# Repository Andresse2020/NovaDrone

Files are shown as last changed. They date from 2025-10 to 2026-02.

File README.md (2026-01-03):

# NovaDrone

Copyright © 2025 Andresse Brisel BASSINGA
Licensed under CERN Open Hardware Licence v2 – Weakly Reciprocal (CERN-OHL-W)

This project provides a complete hardware design for a professional UAV Quadcopter.
Firmware is proprietary and not covered by this licence.

## Project Overview
NovaDrone is a full hardware–firmware engineering project aiming to develop the **entire embedded electronics** of a quadcopter UAV **from scratch**.  
Rather than relying on off-the-shelf components, the project focuses on designing all critical subsystems: propulsion electronics, real-time motor control, power supervision, communication, diagnostics, and later, a fully custom flight controller.

The objective is to create a **professional-grade, reliable, and modular UAV platform** suitable for demanding embedded applications in robotics and aerospace.

---

## Key Features

- **Custom 1.5 kW Propulsion Board**  
  Single PCB integrating four 300–400 W ESCs and a dedicated supervisor MCU.

- **High-Performance ESC Subsystems**  
  STM32G4-based motor controllers using sensorless FOC, 48 kHz PWM, synchronized ADC sampling, and real-time telemetry.

- **Supervisor MCU**  
  Active precharge, power sequencing, battery monitoring, ARM/DISARM logic, watchdog, kill-line, USB monitoring, and DroneCAN communication.

- **Integrated Power Management**  
  LC filtering, TVS protection, OVP/UVLO/OCP/OTP, reinforced copper, and regulated 12 V / 5 V / 3.3 V rails.

- **Communication Architecture**  
  DroneCAN (CAN-FD) for propulsion telemetry and commands, UART CLI for debugging, USB streaming during development.

- **Custom Flight Controller (Next Stage)**  
  IMU fusion, stabilization, navigation logic, modular firmware architecture.

---

## Starting Point

NovaDrone uses a robust quadcopter frame as a mechanical platform for integration and testing:

- **Frame:** ZD550 carbon fiber  
- **Motors:** QM4208 brushless motors  
- **Propellers:** 1455 carbon fiber  

All electronics, power systems, and firmware are entirely custom-designed.

---

## Project Goals

NovaDrone aims to develop a **complete UAV electronics and firmware stack**, with emphasis on:

- High-efficiency propulsion and motor control  
- Intelligent and safe power management  
- Clean and maintainable firmware architecture  
- Robust diagnostics and system telemetry  
- Modular and scalable embedded design  
- Full control over every subsystem (no black boxes)

This is not a drone assembly project—**every subsystem is engineered from the ground up**.

---

## Architecture

### 1. Propulsion Board (1.5 kW)
A single PCB containing all propulsion-related electronics.

**Includes:**
- 4 × ESC (STM32G4)  
- 1 × Supervisor MCU  
- PSU: 12 V / 5 V / 3.3 V  
- Active precharge circuit  
- LC filtering, TVS, fuses  
- CAN-FD transceivers  
- USB and UART  
- XT60 (battery), XT30PW (motors), JST PH/SH, Tag-Connect SWD

---

### 2. ESC Subsystems (300–400 W each)

Each ESC is a fully independent motor controller.

**Features:**
- STM32G4 ARM Cortex-M4  
- Sensorless FOC  
- 48 kHz PWM  
- 24 kHz current loop  
- 1 kHz speed loop  
- Synchronized ADC sampling  
- Low-noise current sensing  
- Telemetry (current, voltage, RPM, temperature)  
- Bare-metal firmware (no HAL)

---

### 3. Supervisor MCU

Handles global power management and safety.

**Functions:**
- Active precharge (anti-inrush)  
- Battery voltage/current/temperature monitoring  
- Power sequencing  
- ARM/DISARM logic  
- Watchdog and kill-line  
- DroneCAN (CAN-FD) communication  
- **USB interface for development-time monitoring**  
- UART CLI  
- Planned: CAN bootloader

---

### 4. Integrated Power Management

Built directly into the propulsion board.

**Includes:**
- Input: LiPo 6S (18–25 V)  
- LC input filtering (PI filter)  
- TVS surge protection  
- OVP, UVLO, OCP, OTP protections  
- Reinforced copper planes  
- Regulated power rails (12 V / 5 V / 3.3 V)

---

### 5. Flight Control Unit (Upcoming)

The FCU will be developed after propulsion system validation.

**Planned capabilities:**
- STM32-based processing  
- IMU, barometer, magnetometer, GPS fusion  
- Kalman-based estimation  
- Stabilization loops  
- Trajectory and navigation control  

---

### 6. Communication System

| Interface | Purpose |
|---|---|
| **DroneCAN (CAN-FD)** | ESC commands, propulsion telemetry, supervisor data |
| **USB** | High-rate logging and real-time monitoring during development |
| **UART CLI** | Debugging, tuning, calibration |
| **SWD** | Low-level flashing and debugging |

---

## Development Environment

NovaDrone firmware uses a custom modular embedded development environment built with **CMake**.

## Licence

Hardware design files are licensed under the CERN Open Hardware Licence v2 – Weakly Reciprocal (CERN-OHL-W).

The firmware is proprietary and not covered by this licence.
Commercial licences are available on request.

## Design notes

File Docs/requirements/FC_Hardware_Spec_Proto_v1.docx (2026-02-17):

HARDWARE SPECIFICATION

Flight Controller — Prototype v1

Parameter | Value
Document ID | HW-SPEC-PROTO-001
Version | 1.0 — Draft
Date | February 2026
Parent document | SYS-REQ-001
Status | Draft
Certification | Not certified — internal validation prototype only

# 1. Purpose

This document specifies the hardware requirements for the design and manufacture of the Flight Controller (FC) Prototype v1. It is intended for the hardware engineer responsible for PCB design, layout, and assembly.

The prototype serves to validate hardware choices prior to the certified DAL-B production design. It is not subject to DO-254 certification at this stage.

# 2. System Architecture

The FC system consists of three separate PCBs interconnected via board-to-board connectors:

Board | PCB Size | Role
FCU (Main Board) | 100 × 100 mm | MCU, inertial sensors, power interfaces, communication
GNSS + Compass Module | External module | u-blox ZOE-M8Q + AK09918C
Remote Control Module | External module | ExpressLRS SX1280 + ESP32-C3

- GNSS and RC modules connect to the FCU via board-to-board stacking connectors (left and right sides of the FCU)
- All three PCBs are 4-layer

## 2.1 Block Diagram

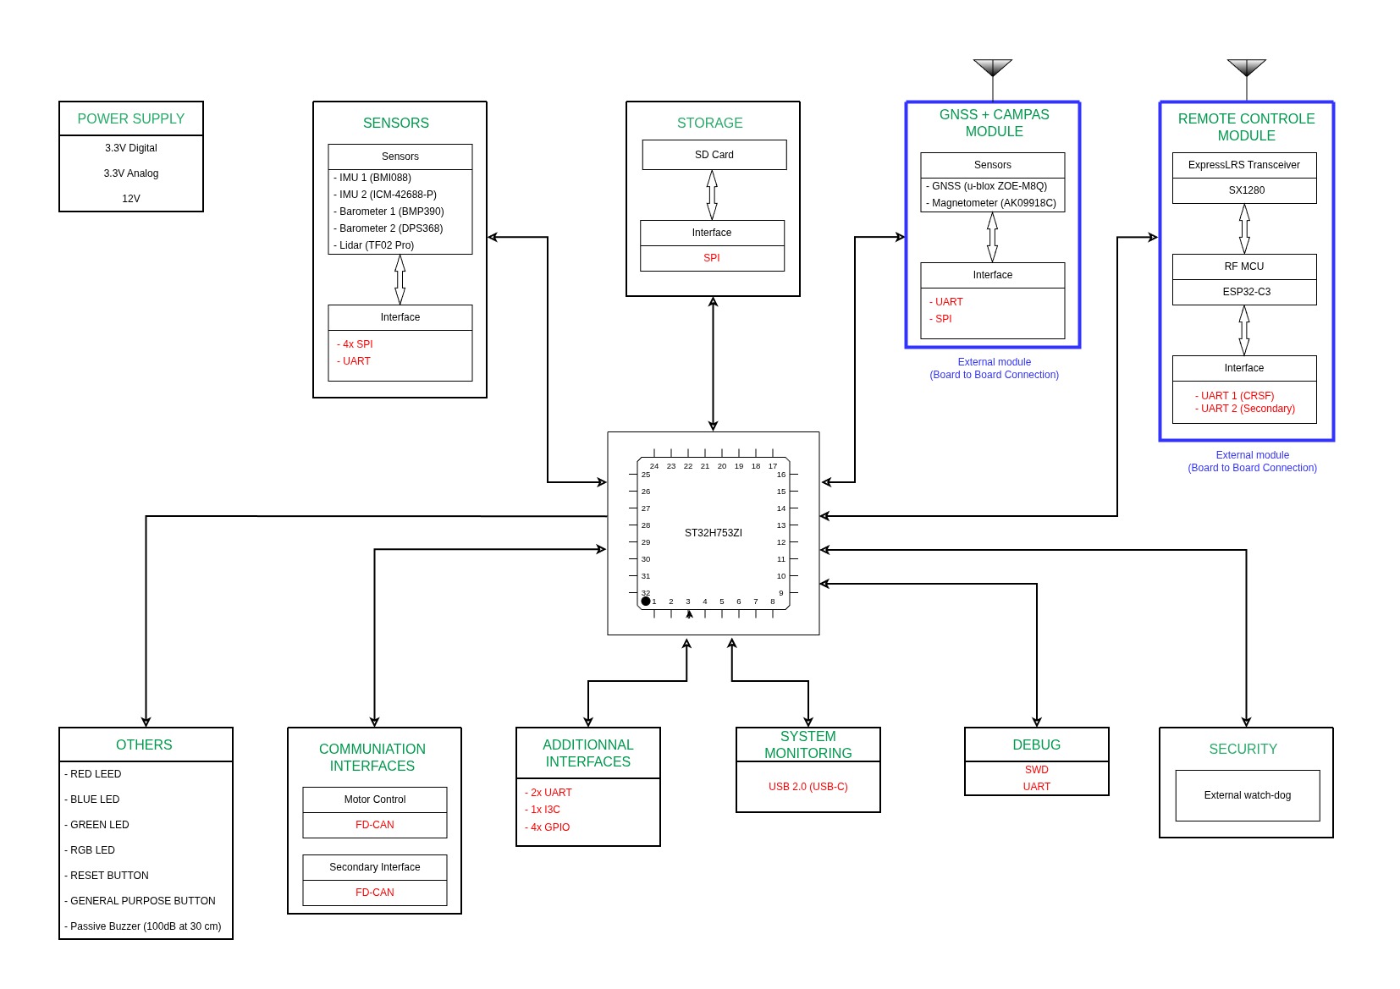
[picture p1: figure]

Figure 1 — FC System Block Diagram

## 2.2 Mechanical Layout

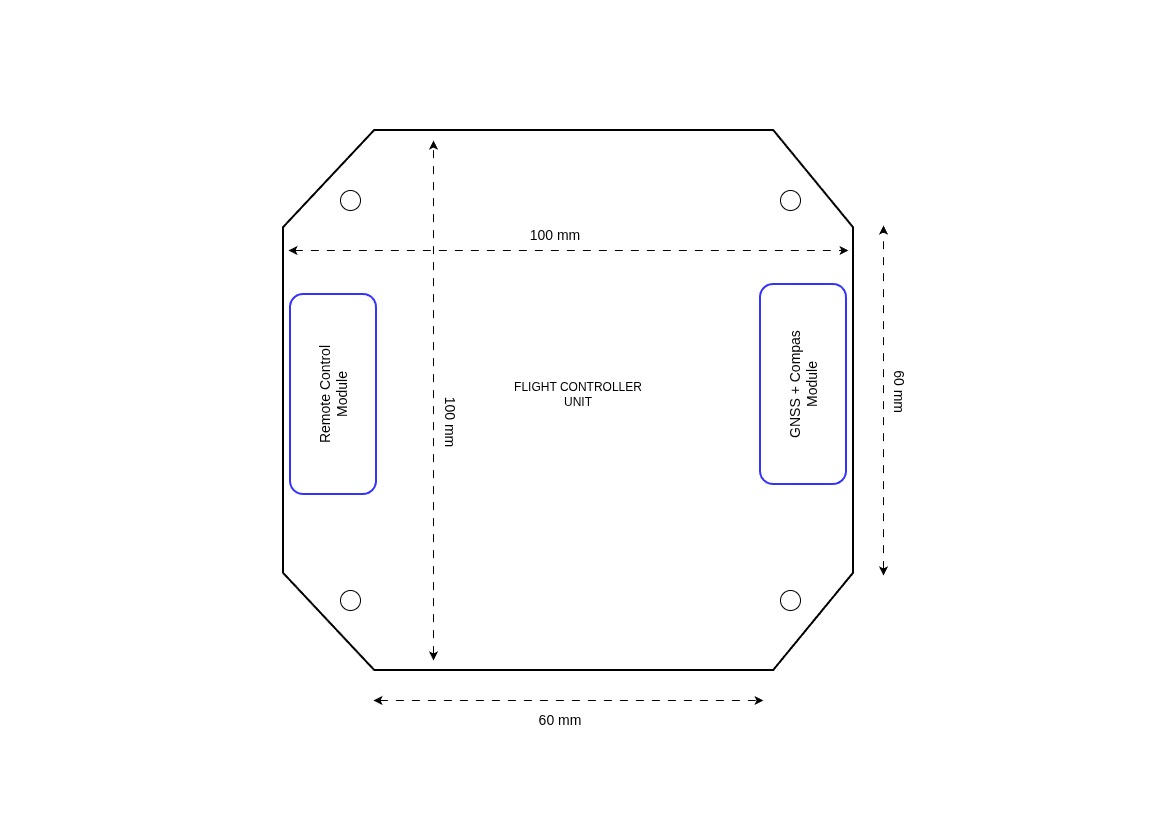
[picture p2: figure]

Figure 2 — FCU Board Layout (100 × 100 mm octagonal, modules on left and right sides)

# 3. Fixed Components

The following critical components are imposed. No substitution without prior validation.

## 3.1 FCU — Main Board

Microcontroller

Parameter | Value
MCU | ST32H753ZI
Architecture | ARM Cortex-M7 @ 480 MHz — hardware double-precision FPU
Justification | 16D EKF @ 1 kHz — SYS-REQ-F-010, SYS-REQ-F-013

Inertial Sensors — Redundancy Required (SYS-REQ-F-001)

Reference | Component | Bus | Rate | Notes
IMU 1 | BMI088 | SPI | ≥ 1 kHz | Gyro + Accel
IMU 2 | ICM-42688-P | SPI | ≥ 1 kHz | Gyro + Accel
Barometer 1 | BMP390 | SPI | ≥ 50 Hz
Barometer 2 | DPS368 | SPI | ≥ 50 Hz

IMPORTANT: Both IMUs and both barometers must be mounted on vibration isolation pads (soft-mount).

Distance Sensor

Reference | Component | Bus | Rate
Lidar | TF02 Pro | UART | ≥ 50 Hz — SYS-REQ-F-001

## 3.2 GNSS + Compass Module (external board)

Reference | Component | Interface to FCU | Rate
GNSS | u-blox ZOE-M8Q | UART | ≥ 5 Hz — SYS-REQ-F-001
Magnetometer | AK09918C | SPI | ≥ 50 Hz — SYS-REQ-F-001

- External GNSS antenna via U.FL or SMA connector
- Module positioned on the right/left side of the FCU (see Figure 2)

## 3.3 Remote Control Module (external board)

Reference | Component | Interface to FCU | Notes
RF Transceiver | SX1280 | SPI (via ESP32-C3) | ExpressLRS — SYS-REQ-IF-001
RF MCU | ESP32-C3 | UART CRSF to FCU | Primary CRSF protocol

- FCU interfaces: UART 1 (CRSF primary) + UART 2 (secondary)
- Module positioned on the left/right side of the FCU (see Figure 2)

# 4. Power Supply

The FCU has no direct access to the battery. All power rails are supplied by the propulsion board via dedicated JST-PH 2-pin connectors (one per rail). Maximum current per rail: 2A.

Rail | Voltage | Max Current | Connector | Usage
3.3V Digital | 3.3V regulated | 2A | JST-PH 2-pin | MCU, digital sensors, logic
3.3V Analog | 3.3V regulated | 2A | JST-PH 2-pin | Analog sensors, MCU ADC — filtered, isolated from digital rail
12V Regulated | 12V regulated | 2A | JST-PH 2-pin | Buzzer, peripherals

NOTE: The FCU does not include any DC-DC converters or LDOs for these rails. The three JST-PH connectors are the sole power inputs from the propulsion board. Current monitoring is not available on the FCU side.

Battery voltage and current monitoring (SYS-REQ-PWR-001/002) are provided by the propulsion board and transmitted to the FCU via CAN bus.

# 5. PCB Specifications

Parameter | Specification
FCU dimensions | 100 × 100 mm — octagonal shape (chamfered corners)
Module dimensions | Not specified
Number of layers | 4 layers — all boards
Mounting holes FCU | 4× M3 — one at each corner
Module mounting | Board-to-board stacking connectors, lateral overhang

# 6. Required Interfaces

## 6.1 Sensor Interfaces (FCU)

Bus | Qty | Assignment | Notes
SPI | 4× | IMU1, IMU2, Baro1, Baro2 | Dedicated CS per sensor
UART | 1× | Lidar TF02 Pro | Verify TF02 operating voltage (5V or 3.3V)

## 6.2 Motor Control Interface (FCU)

Interface | Qty | Usage
FD-CAN | 2× | Motor control (CAN Bus) — SYS-REQ-F-020

NOTE: FD-CAN is selected for motor control. ESCs are CAN-compatible.

## 6.3 Additional Communication Interfaces (FCU)

Interface | Qty | Usage
UART | 2× | Additional interfaces (e.g. telemetry, expansion)
I3C/I2C | 1× | Additional interface
GPIO | 4× | General purpose

## 6.4 System Interfaces (FCU)

Interface | Qty | Usage
USB-C | 1× | System monitoring (USB 2.0) — SYS-REQ-NF-030
SWD | 1× | MCU programming and debug
UART debug | 1× | MCU serial debug
SD Card | 1× | Flight data logging — SYS-REQ-IF-011 (SPI bus)

## 6.5 Board-to-Board Interfaces (FCU ↔ Modules)

Connection | Direction | Signals
FCU ↔ GNSS+Compass | Board-to-board | UART, SPI, 3.3V Digital, GND
FCU ↔ RC Module | Board-to-board | UART1 (CRSF), UART2, 3.3V Digital, GND

Connector reference, pitch, and stack height are left to the hardware engineer's judgment based on mechanical constraints and availability.

# 7. Visual and Audio Indicators

Component | Specification | SYS-REQ
Red LED | 1× red LED — critical state | SYS-REQ-ARM-003
Blue LED | 1× blue LED — info state | SYS-REQ-ARM-003
Green LED | 1× green LED — armed / OK | SYS-REQ-ARM-003
RGB LED | 1× RGB LED — general status | SYS-REQ-ARM-003
Passive Buzzer | 100 dB at 30 cm | SYS-REQ-ARM-003

# 8. Physical Controls

Element | Specification
RESET button | 1× push button — MCU reset
General purpose btn | 1× push button — configurable (e.g. manual arming)

# 9. Hardware Security

Element | Specification
External watchdog | 1× hardware watchdog — 500 ms timeout — SYS-REQ-NF-023
Justification | System reset if not refreshed by MCU — protects against software lockup

# 10. Timing Requirements

These constraints are critical for the flight control loop. The hardware engineer must ensure all interfaces support the following data rates.

Loop / Sensor | Rate / Period | Reference
IMU (gyro + accel) | ≥ 1 kHz | SYS-REQ-F-013, SYS-REQ-NF-010
Fast control loop (rate) | 1 ms — max jitter 0.2 ms | SYS-REQ-NF-010
Medium control (attitude) | 5 ms — max jitter 0.5 ms | SYS-REQ-NF-010
Barometer | ≥ 50 Hz | SYS-REQ-F-001
GNSS | ≥ 5 Hz | SYS-REQ-F-001
Telemetry / Logging | ≥ 1 Hz / ≥ 10 Hz | SYS-REQ-IF-005, SYS-REQ-IF-012

# 11. Deliverables

# | Deliverable | Details

1 | Schematic | PDF + source file (KiCad)
2 | PCB layout | Gerber files + drill files
3 | BOM | Manufacturer references, quantities, suppliers
4 | Design notes | Key decisions, known limitations, simulation results

# 12. Acceptance Criteria

The prototype is considered acceptable when all of the following checks pass:

# | Criterion | Reference

1 | MCU boots successfully in < 5 seconds | SYS-REQ-SM-002
2 | IMU 1 (BMI088) readable at 1 kHz via SPI | SYS-REQ-F-001
3 | IMU 2 (ICM-42688-P) readable at 1 kHz via SPI | SYS-REQ-F-001
4 | Barometer 1 (BMP390) and Barometer 2 (DPS368) readable at 50 Hz | SYS-REQ-F-001
5 | GNSS (ZOE-M8Q) — fix acquired, data @ 5 Hz | SYS-REQ-F-001
6 | Magnetometer (AK09918C) readable at 50 Hz | SYS-REQ-F-001
7 | Lidar (TF02 Pro) readable via UART at 50 Hz | SYS-REQ-F-001
8 | SD Card — read/write functional | SYS-REQ-IF-011
9 | FD-CAN — frame transmitted and received on both buses | SYS-REQ-F-020
10 | USB-C — serial communication active | SYS-REQ-NF-030
11 | External watchdog — system reset triggered if not refreshed in 500ms | SYS-REQ-NF-023
12 | All three power rails stable under load (3.3V dig, 3.3V ana, 12V) | SYS-REQ-PWR-001
13 | RGB LED + red/blue/green LEDs — all functional | SYS-REQ-ARM-003
14 | Buzzer — tone audible at 30 cm | SYS-REQ-ARM-003
15 | IMU loop jitter < 0.2 ms (measured via oscilloscope or GPIO toggle) | SYS-REQ-NF-010

# 13. Design Freedom

The following design decisions are left to the hardware engineer's judgment:

- Board-to-board connector selection (pitch, stack height, manufacturer reference)
- External connectors type and reference (JST-GH recommended but not mandatory)
- Component placement and PCB routing
- Analog power rail filtering strategy (EMI filters, ferrite beads, decoupling)
- Passive component footprints

# Revision History

Version | Date | Author | Changes
1.0 | Feb. 2026 | BASSINGA Brisel Andresse | Initial release

Hardware Specification — Flight Controller Prototype v1 PUBLIC

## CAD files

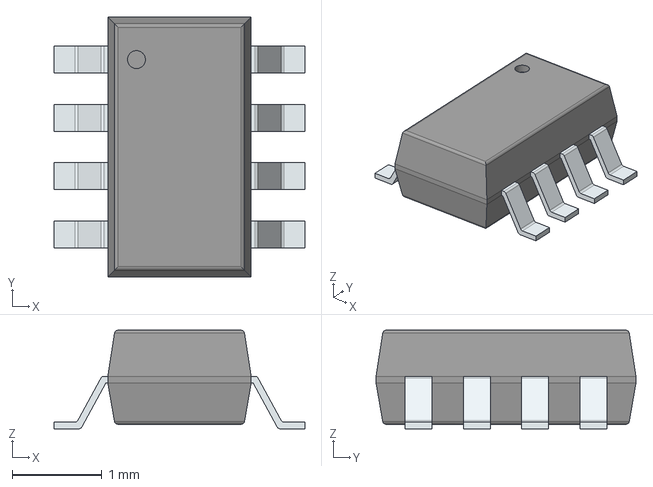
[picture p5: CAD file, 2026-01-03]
GNSS-Module/BassingaLib/BassinaLib_Com_Interfaces/3D/TCAN3403DDFRQ1.stp
2.80 x 2.90 x 1.10 mm
PinsArrayLR

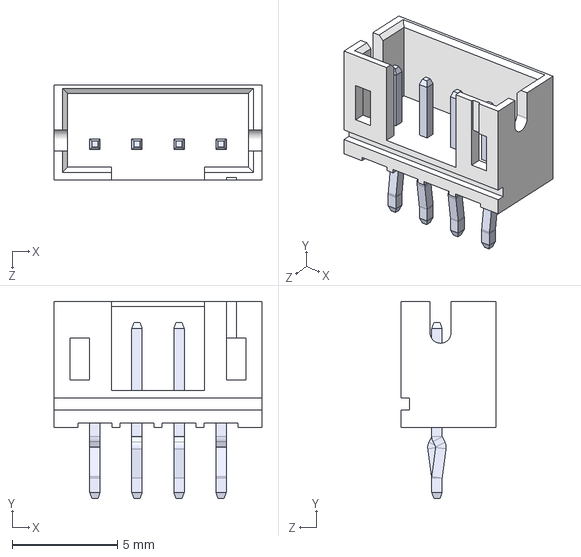
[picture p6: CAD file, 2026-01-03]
GNSS-Module/BassingaLib/BassinaLib_Connectors/3D/B4B-PH-K-S_LF__SN_.step
9.90 x 9.40 x 4.50 mm

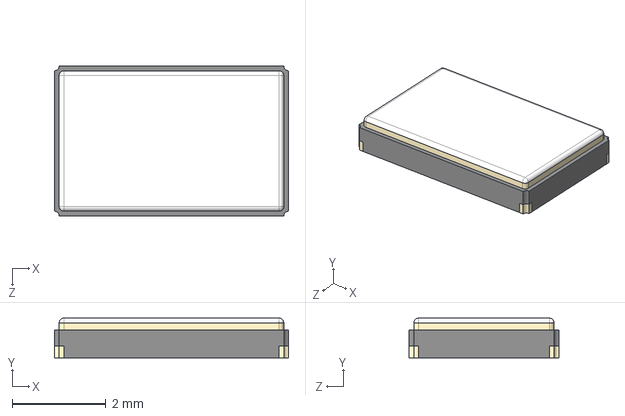
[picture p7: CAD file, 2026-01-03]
GNSS-Module/BassingaLib/BassinaLib_Crystals/3D/ECS-80-10-30B-CWN-TR.stp
5.00 x 0.85 x 3.20 mm

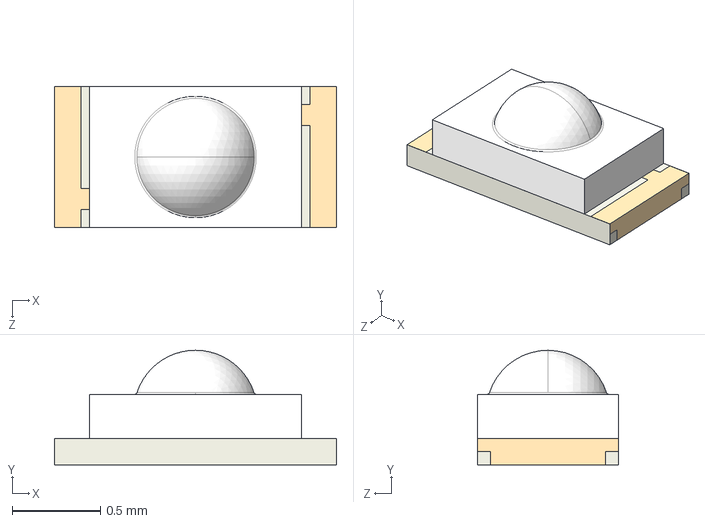
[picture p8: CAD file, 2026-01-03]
GNSS-Module/BassingaLib/BassinaLib_LEDs/3D/APHD1608LCGCK.STEP
1.60 x 0.65 x 0.8 mm

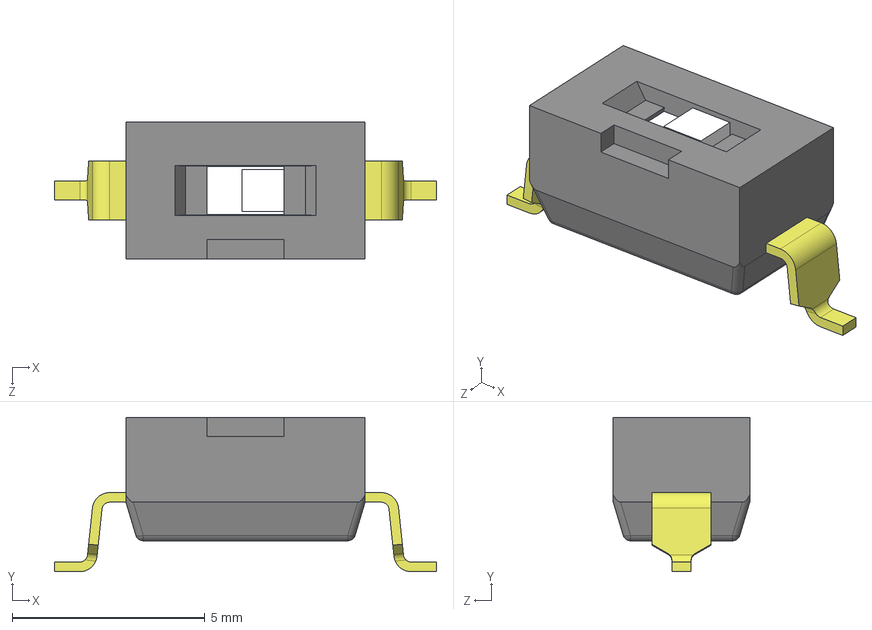
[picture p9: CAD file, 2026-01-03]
GNSS-Module/BassingaLib/BassinaLib_Switch/3D/DS04-254-2-01BK-SMT.stp
9.90 x 4.00 x 3.54 mm

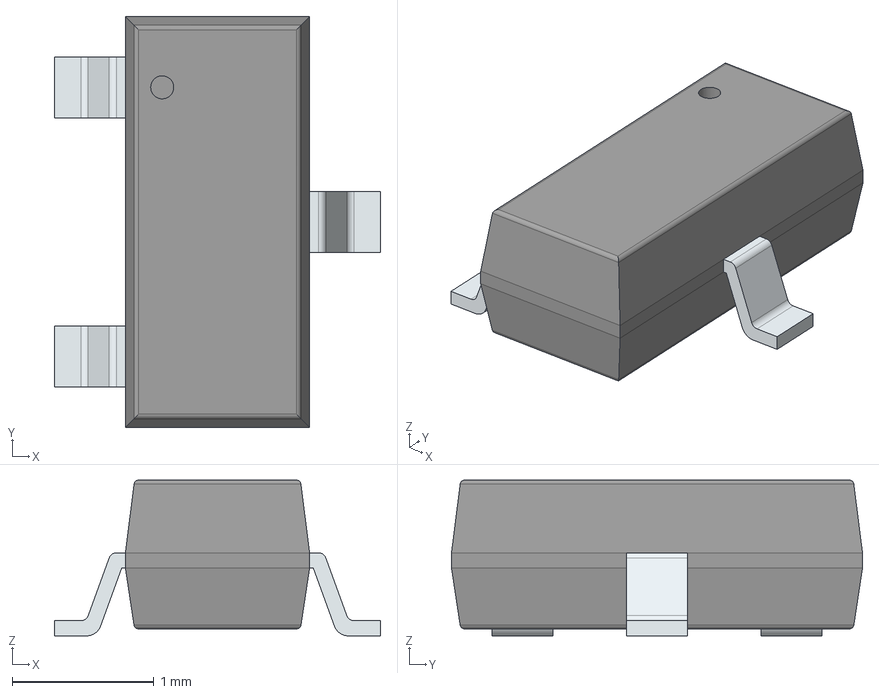
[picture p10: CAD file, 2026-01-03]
GNSS-Module/BassingaLib/BassingaLib_BJT/3D/BC846B.stp
2.30 x 2.90 x 1.10 mm
PinsArrayL
FilletPinR

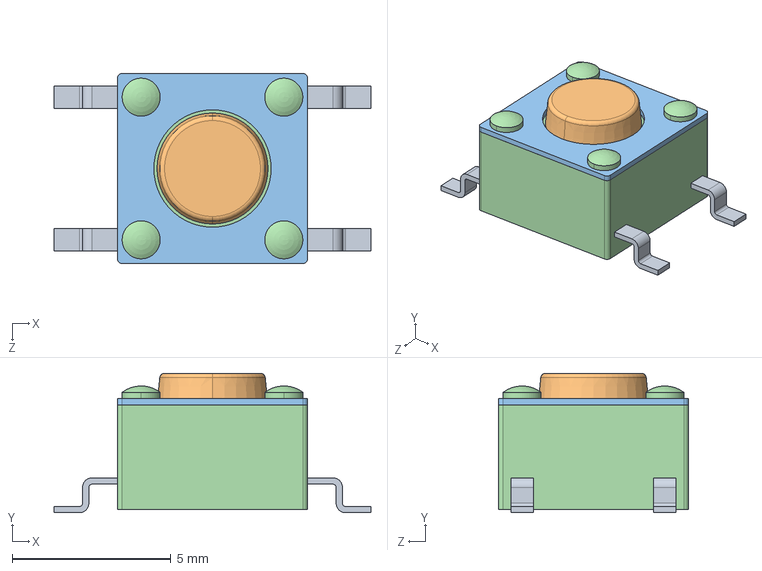
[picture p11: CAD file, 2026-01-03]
GNSS-Module/BassingaLib/BassingaLib_Button/3D/TS04-66-43-BK-260-SMT.stp
10.0 x 4.40 x 6.00 mm

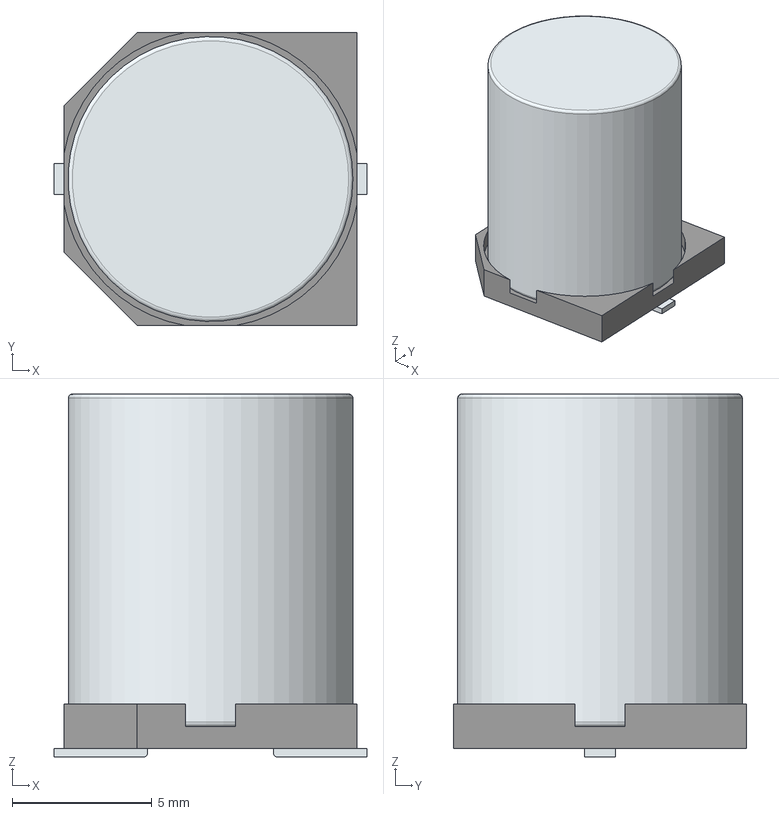
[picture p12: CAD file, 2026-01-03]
GNSS-Module/BassingaLib/BassingaLib_Capacitors/3D/GXC1V331MCW1GS.stp
11.2 x 10.5 x 13.0 mm
Base
Pin1Fillet
Pin2Fillet

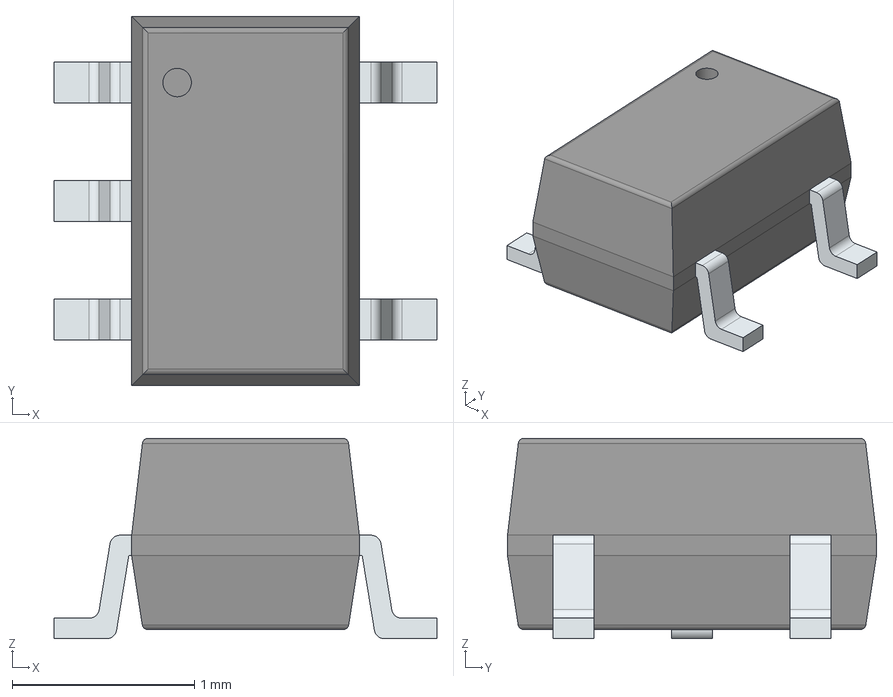
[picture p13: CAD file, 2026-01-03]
GNSS-Module/BassingaLib/BassingaLib_Comparators/3D/MIC841HYC5-TR.stp
2.10 x 2.02 x 1.10 mm
PinsArrayL
PinsArrayR

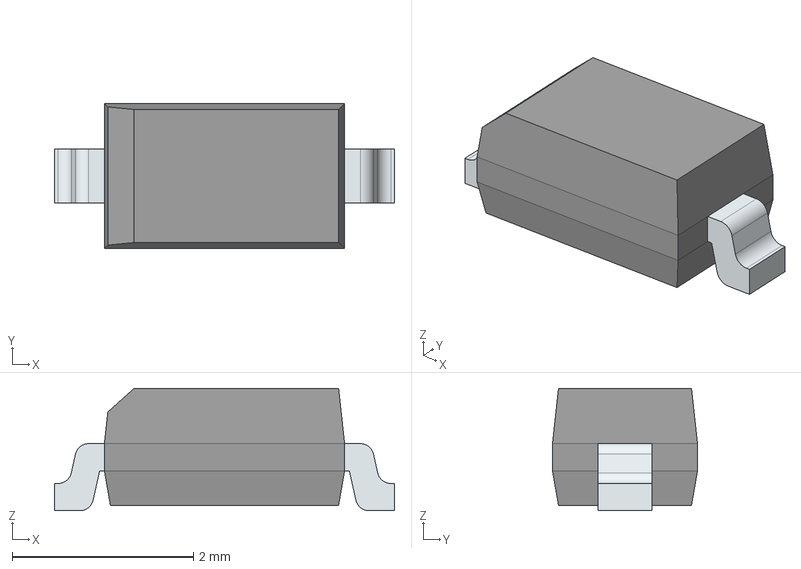
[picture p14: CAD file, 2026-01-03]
GNSS-Module/BassingaLib/BassingaLib_Diodes/3D/SS0540_R1_00001.stp
3.75 x 1.60 x 1.35 mm
FilletPinL
FilletPinR

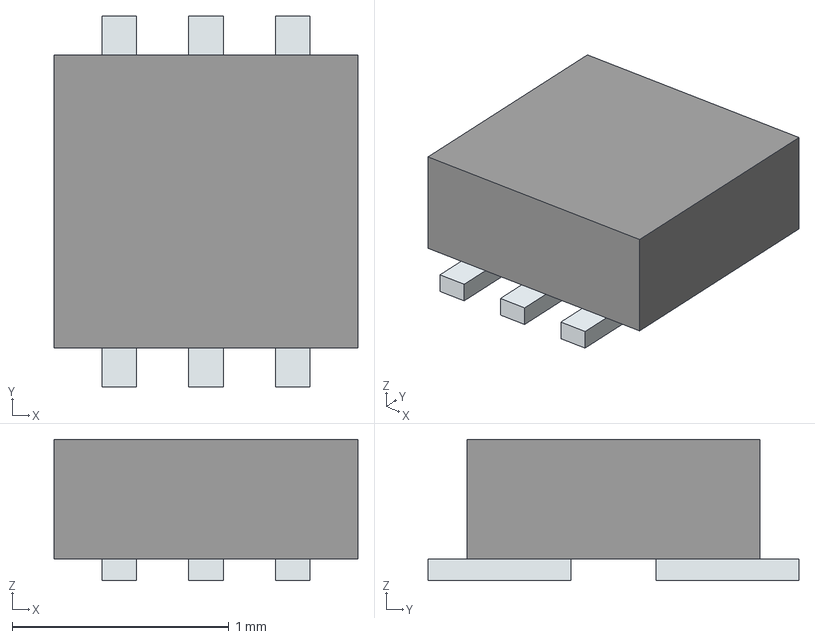
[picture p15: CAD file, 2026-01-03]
GNSS-Module/BassingaLib/BassingaLib_ESD_Protection/3D/ECMF2-40A100N6.stp
1.40 x 1.71 x 0.65 mm
Pins

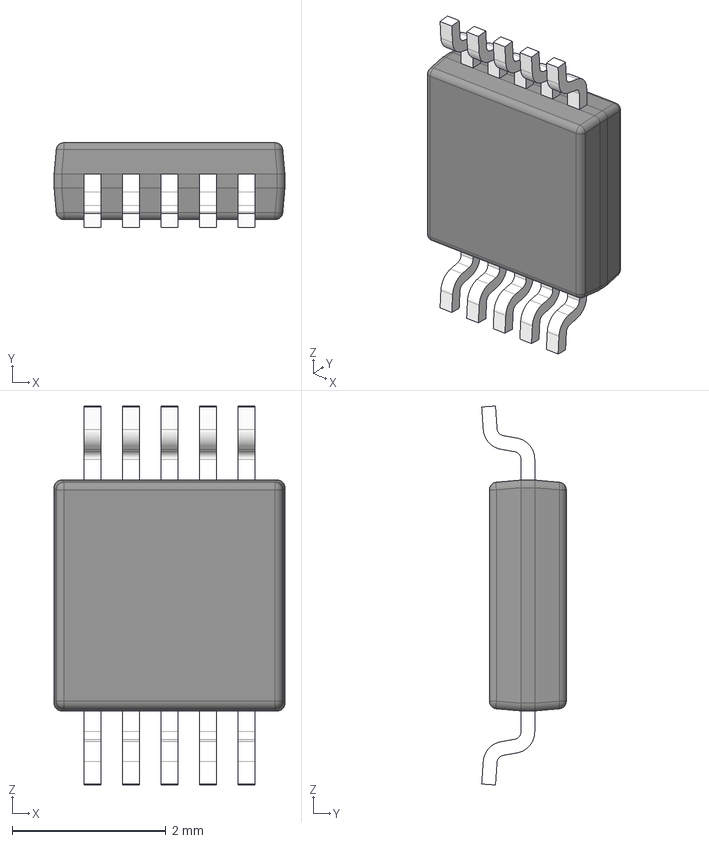
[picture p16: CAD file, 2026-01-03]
GNSS-Module/BassingaLib/BassingaLib_Gate_Drivers/3D/LM5060MMX_NOPB.stp
3.00 x 1.10 x 4.93 mm
BODY-SO
LEAD-SO x 10
PIN1-ID

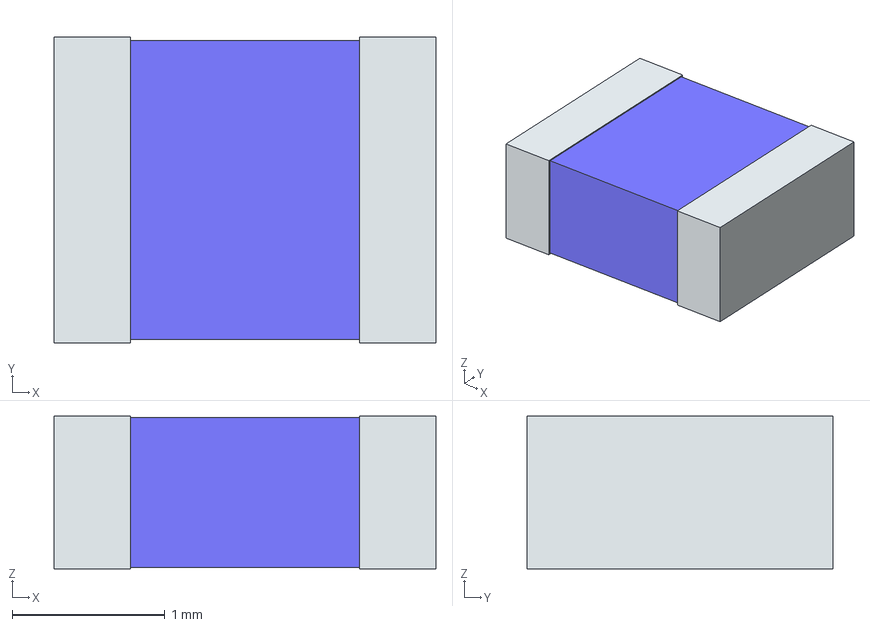
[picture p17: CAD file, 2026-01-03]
GNSS-Module/BassingaLib/BassingaLib_Inductors/3D/SRP3212-3R3M.stp
2.50 x 2.00 x 1.00 mm
term1
term2

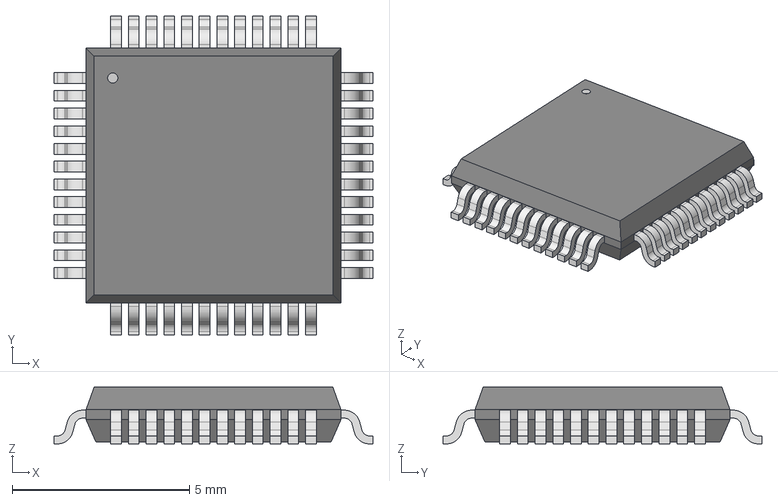
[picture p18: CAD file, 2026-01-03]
GNSS-Module/BassingaLib/BassingaLib_MCU/3D/STM32G473CCT3.stp
8.99 x 8.99 x 1.60 mm

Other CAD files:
GNSS-Module/BassingaLib/BassingaLib_Mosfets/3D/NTMFS5H600NLT1G.stp
GNSS-Module/BassingaLib/BassingaLib_Op_Amp/3D/LM321LVIDBVR.stp
GNSS-Module/BassingaLib/BassingaLib_Sensors/3D/INA181A1IDBVR.stp
GNSS-Module/BassingaLib/BassingaLib_TVS/3D/VCAN33A2-03G-E3-08.stp
GNSS-Module/BassingaLib/BassinaLib_Connectors/3D/4328.step
GNSS-Module/BassingaLib/BassinaLib_Connectors/3D/B2B-PH-K-S.step
GNSS-Module/BassingaLib/BassinaLib_Connectors/3D/BM03B-SRSS-TB_LF__SN_.step
GNSS-Module/BassingaLib/BassinaLib_Connectors/3D/BM05B-SRSS-TB_LF__SN_.step
GNSS-Module/BassingaLib/BassinaLib_Connectors/3D/M20-7832046.stp
GNSS-Module/BassingaLib/BassinaLib_Connectors/3D/MR30PW-FB.stp
GNSS-Module/BassingaLib/BassinaLib_Connectors/3D/MR30PW-M.step
GNSS-Module/BassingaLib/BassinaLib_Connectors/3D/S4B-PH-K-S_LF__SN_.stp
GNSS-Module/BassingaLib/BassinaLib_Connectors/3D/S4B-PH-SM4-TB_LF__SN_.stp
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

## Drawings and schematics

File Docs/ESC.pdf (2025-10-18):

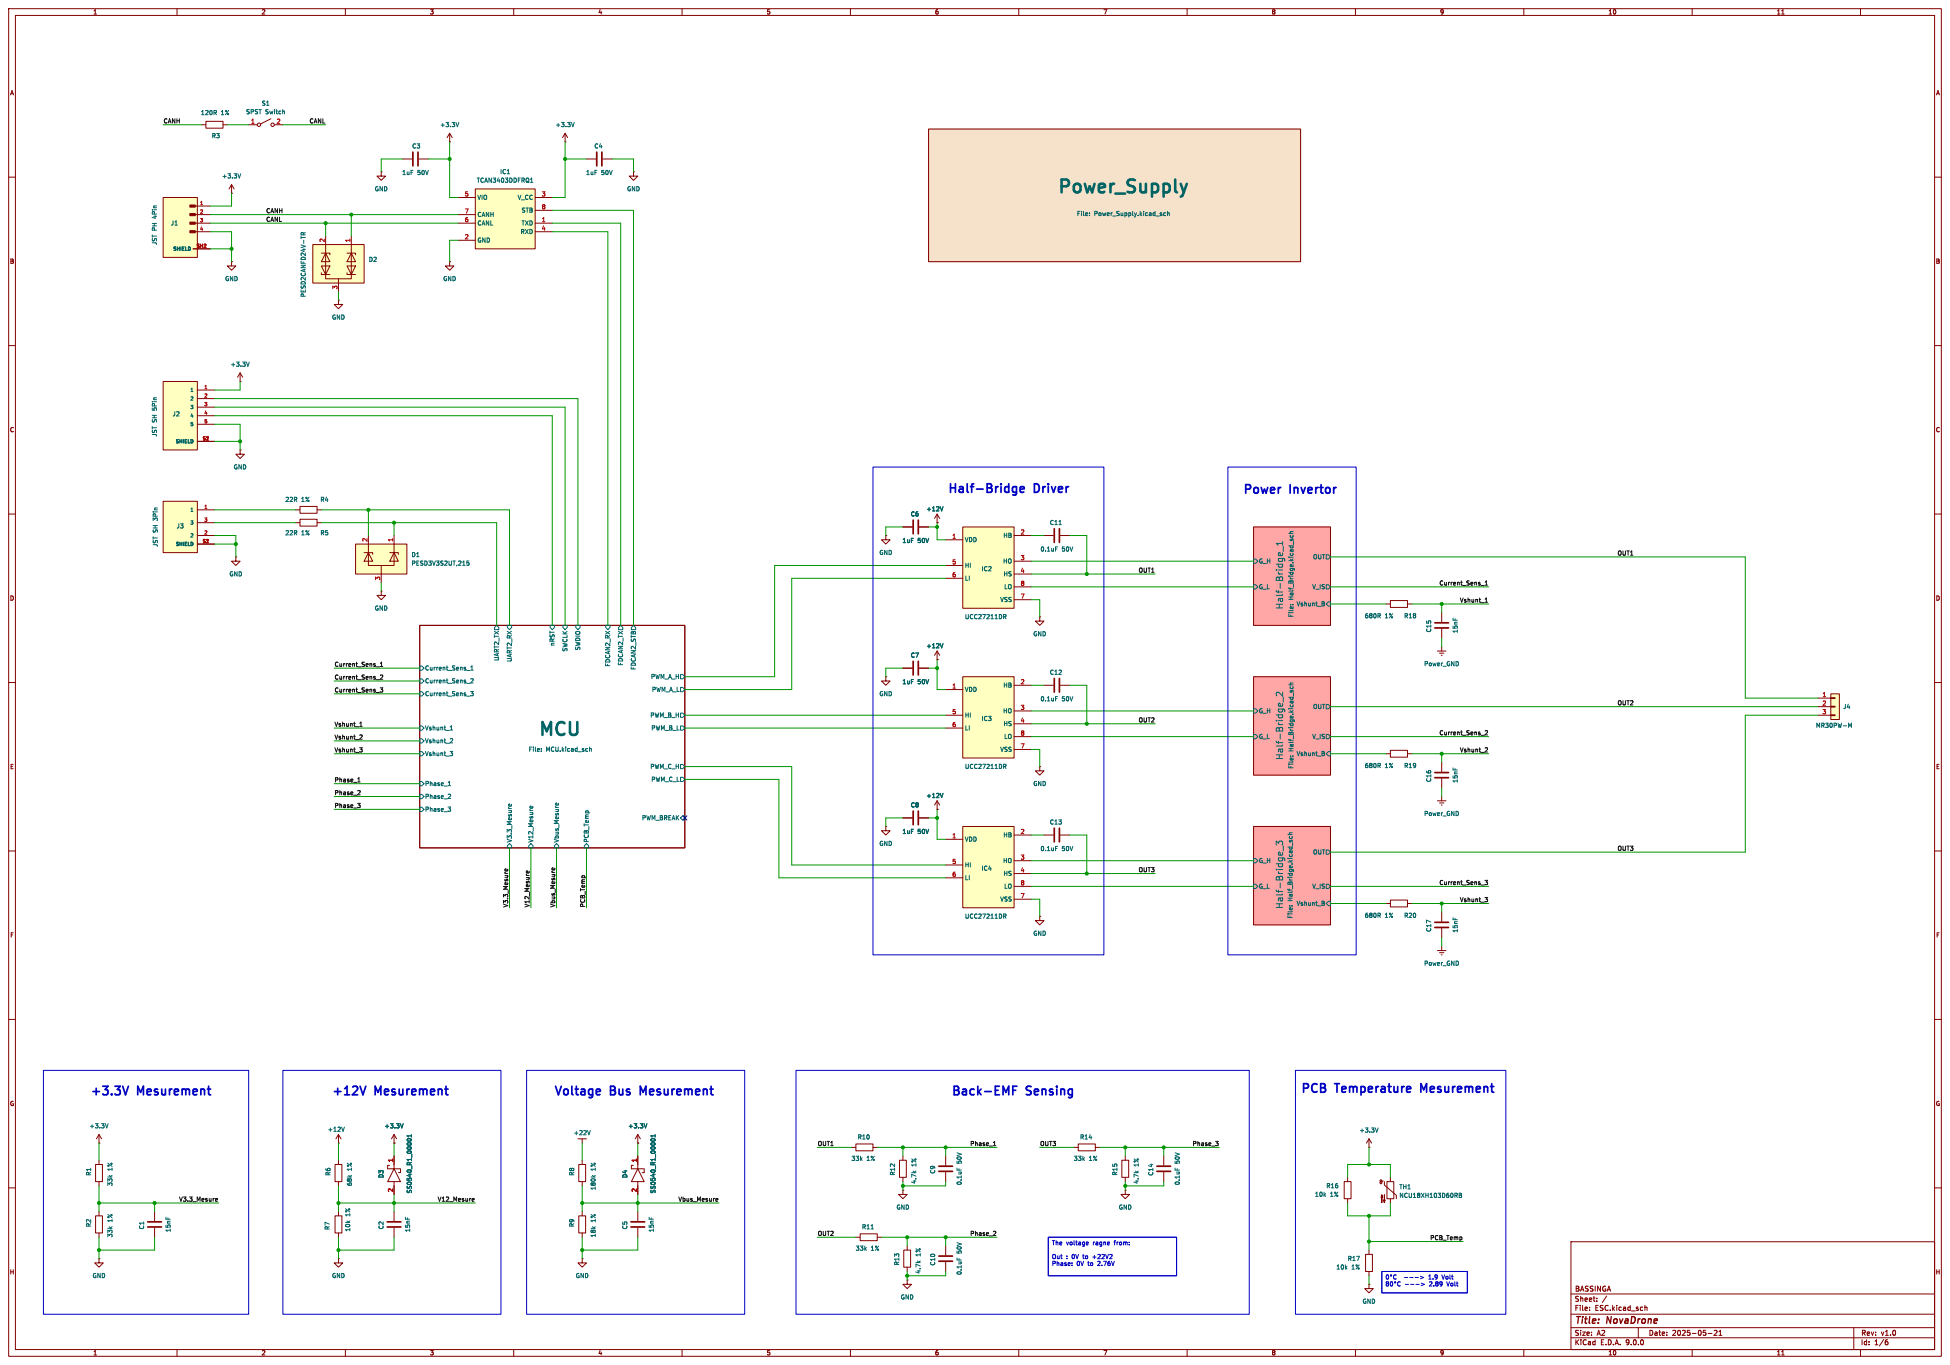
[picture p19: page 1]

The voltage ragne from: Out : 0V to +22V2 Phase: 0V to 2.76V

File: ESC.kicad_sch Sheet: / BASSINGA

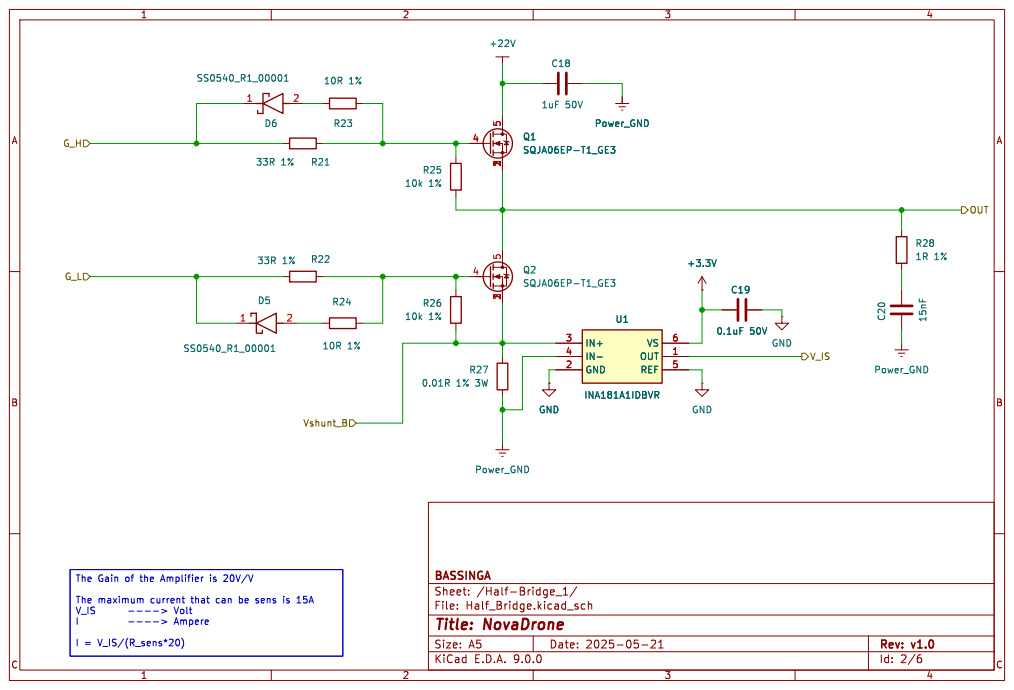
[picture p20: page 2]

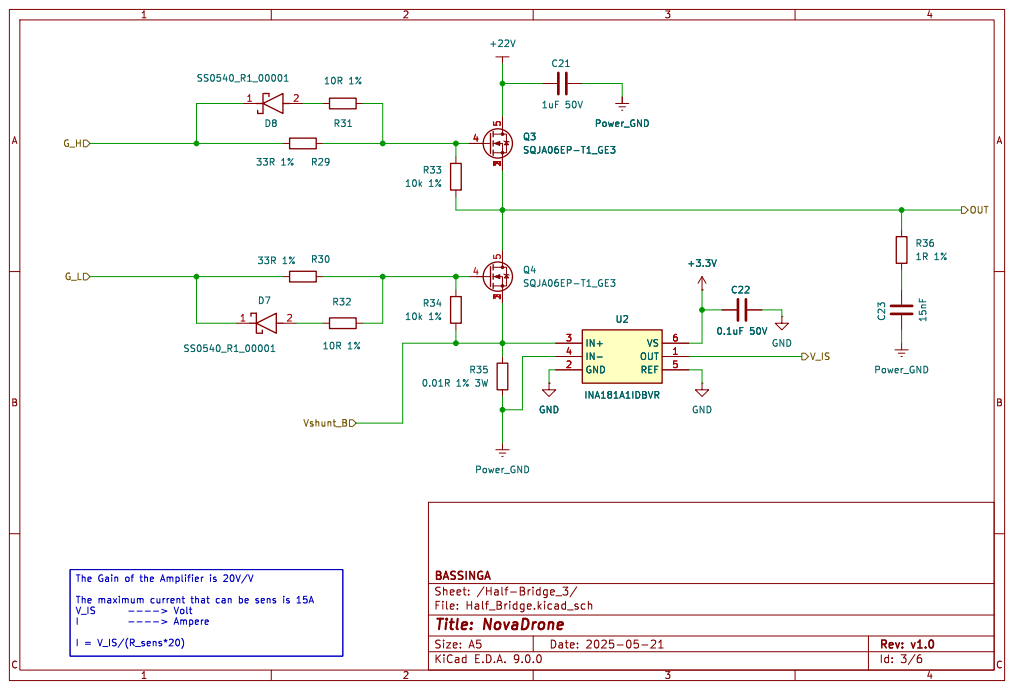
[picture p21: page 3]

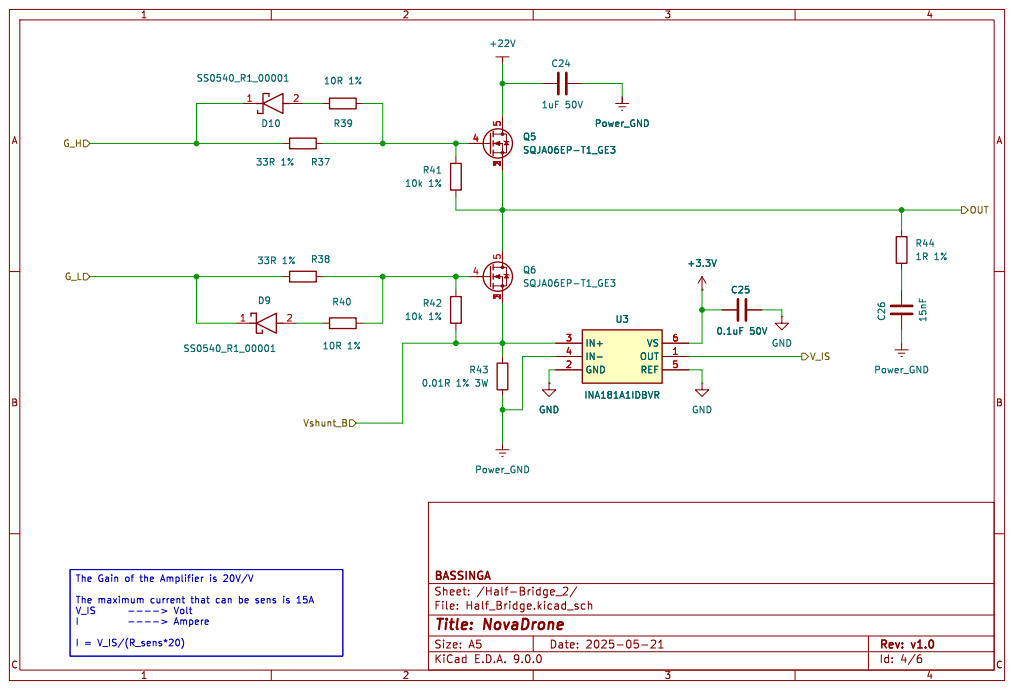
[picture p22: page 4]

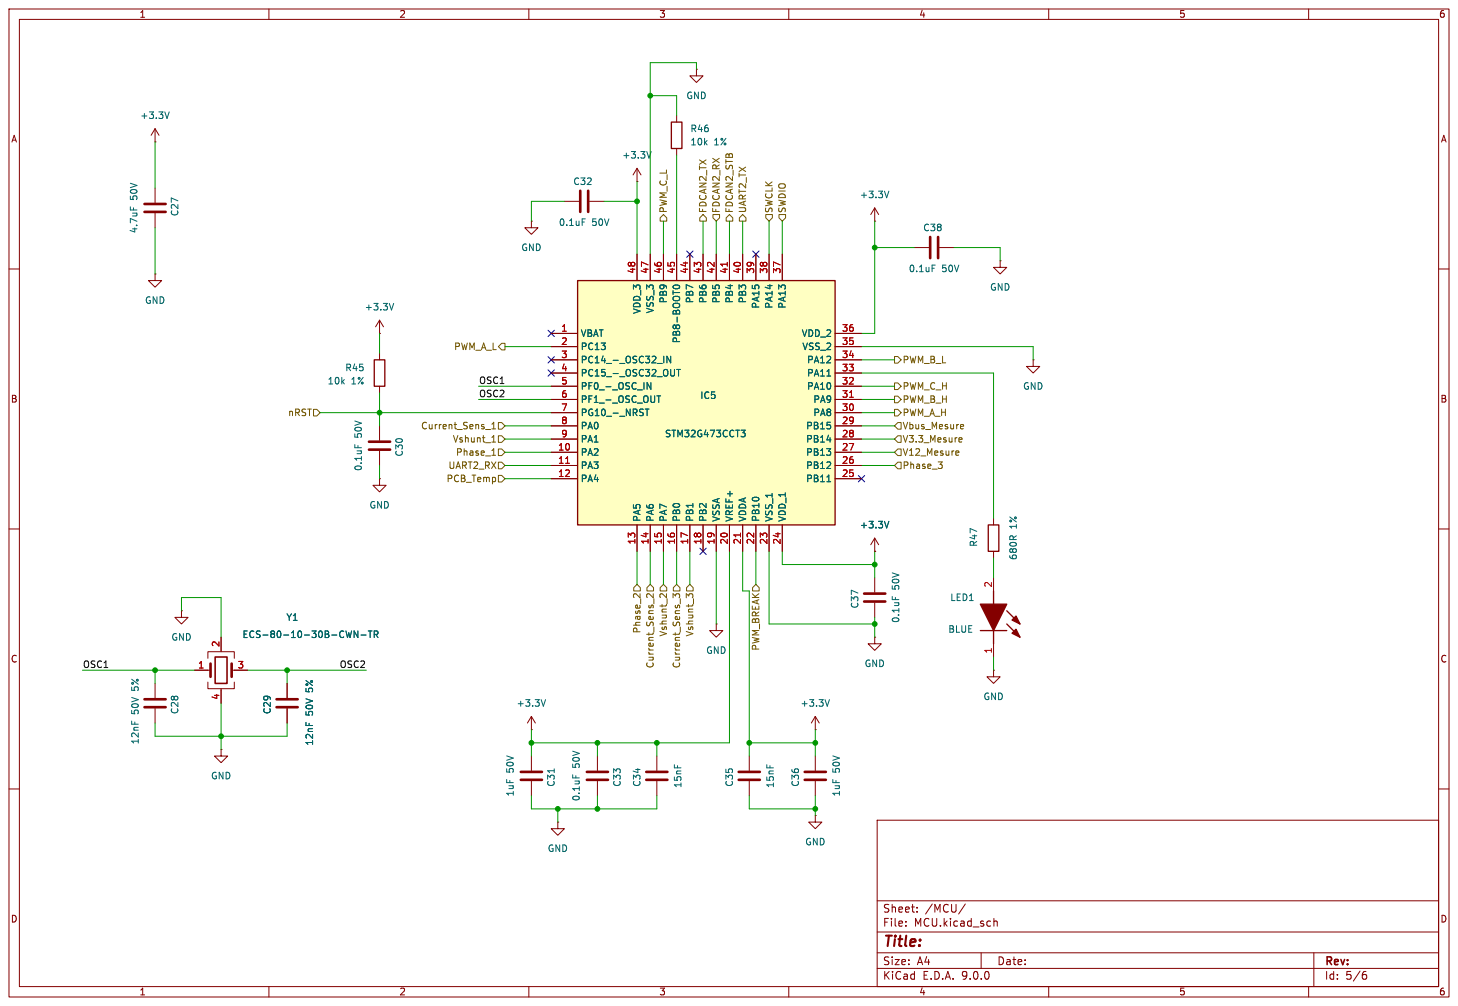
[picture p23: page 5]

Id: 5/6 Title: File: MCU.kicad_sch Sheet: /MCU/

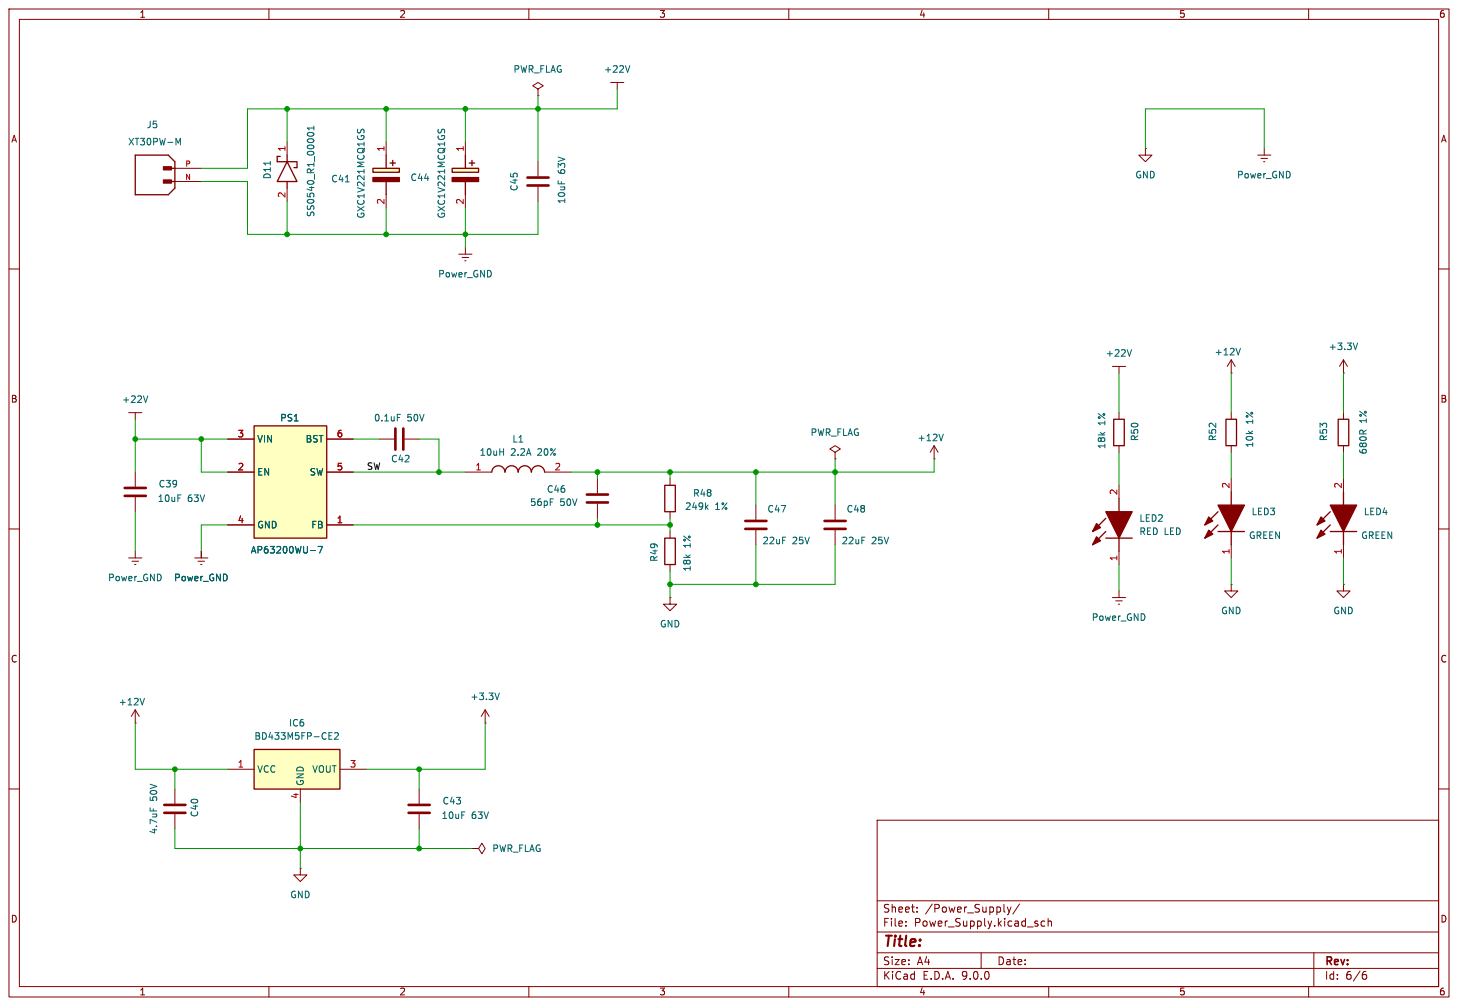
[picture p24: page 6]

Id: 6/6 Title: File: Power_Supply.kicad_sch Sheet: /Power_Supply/ +12V

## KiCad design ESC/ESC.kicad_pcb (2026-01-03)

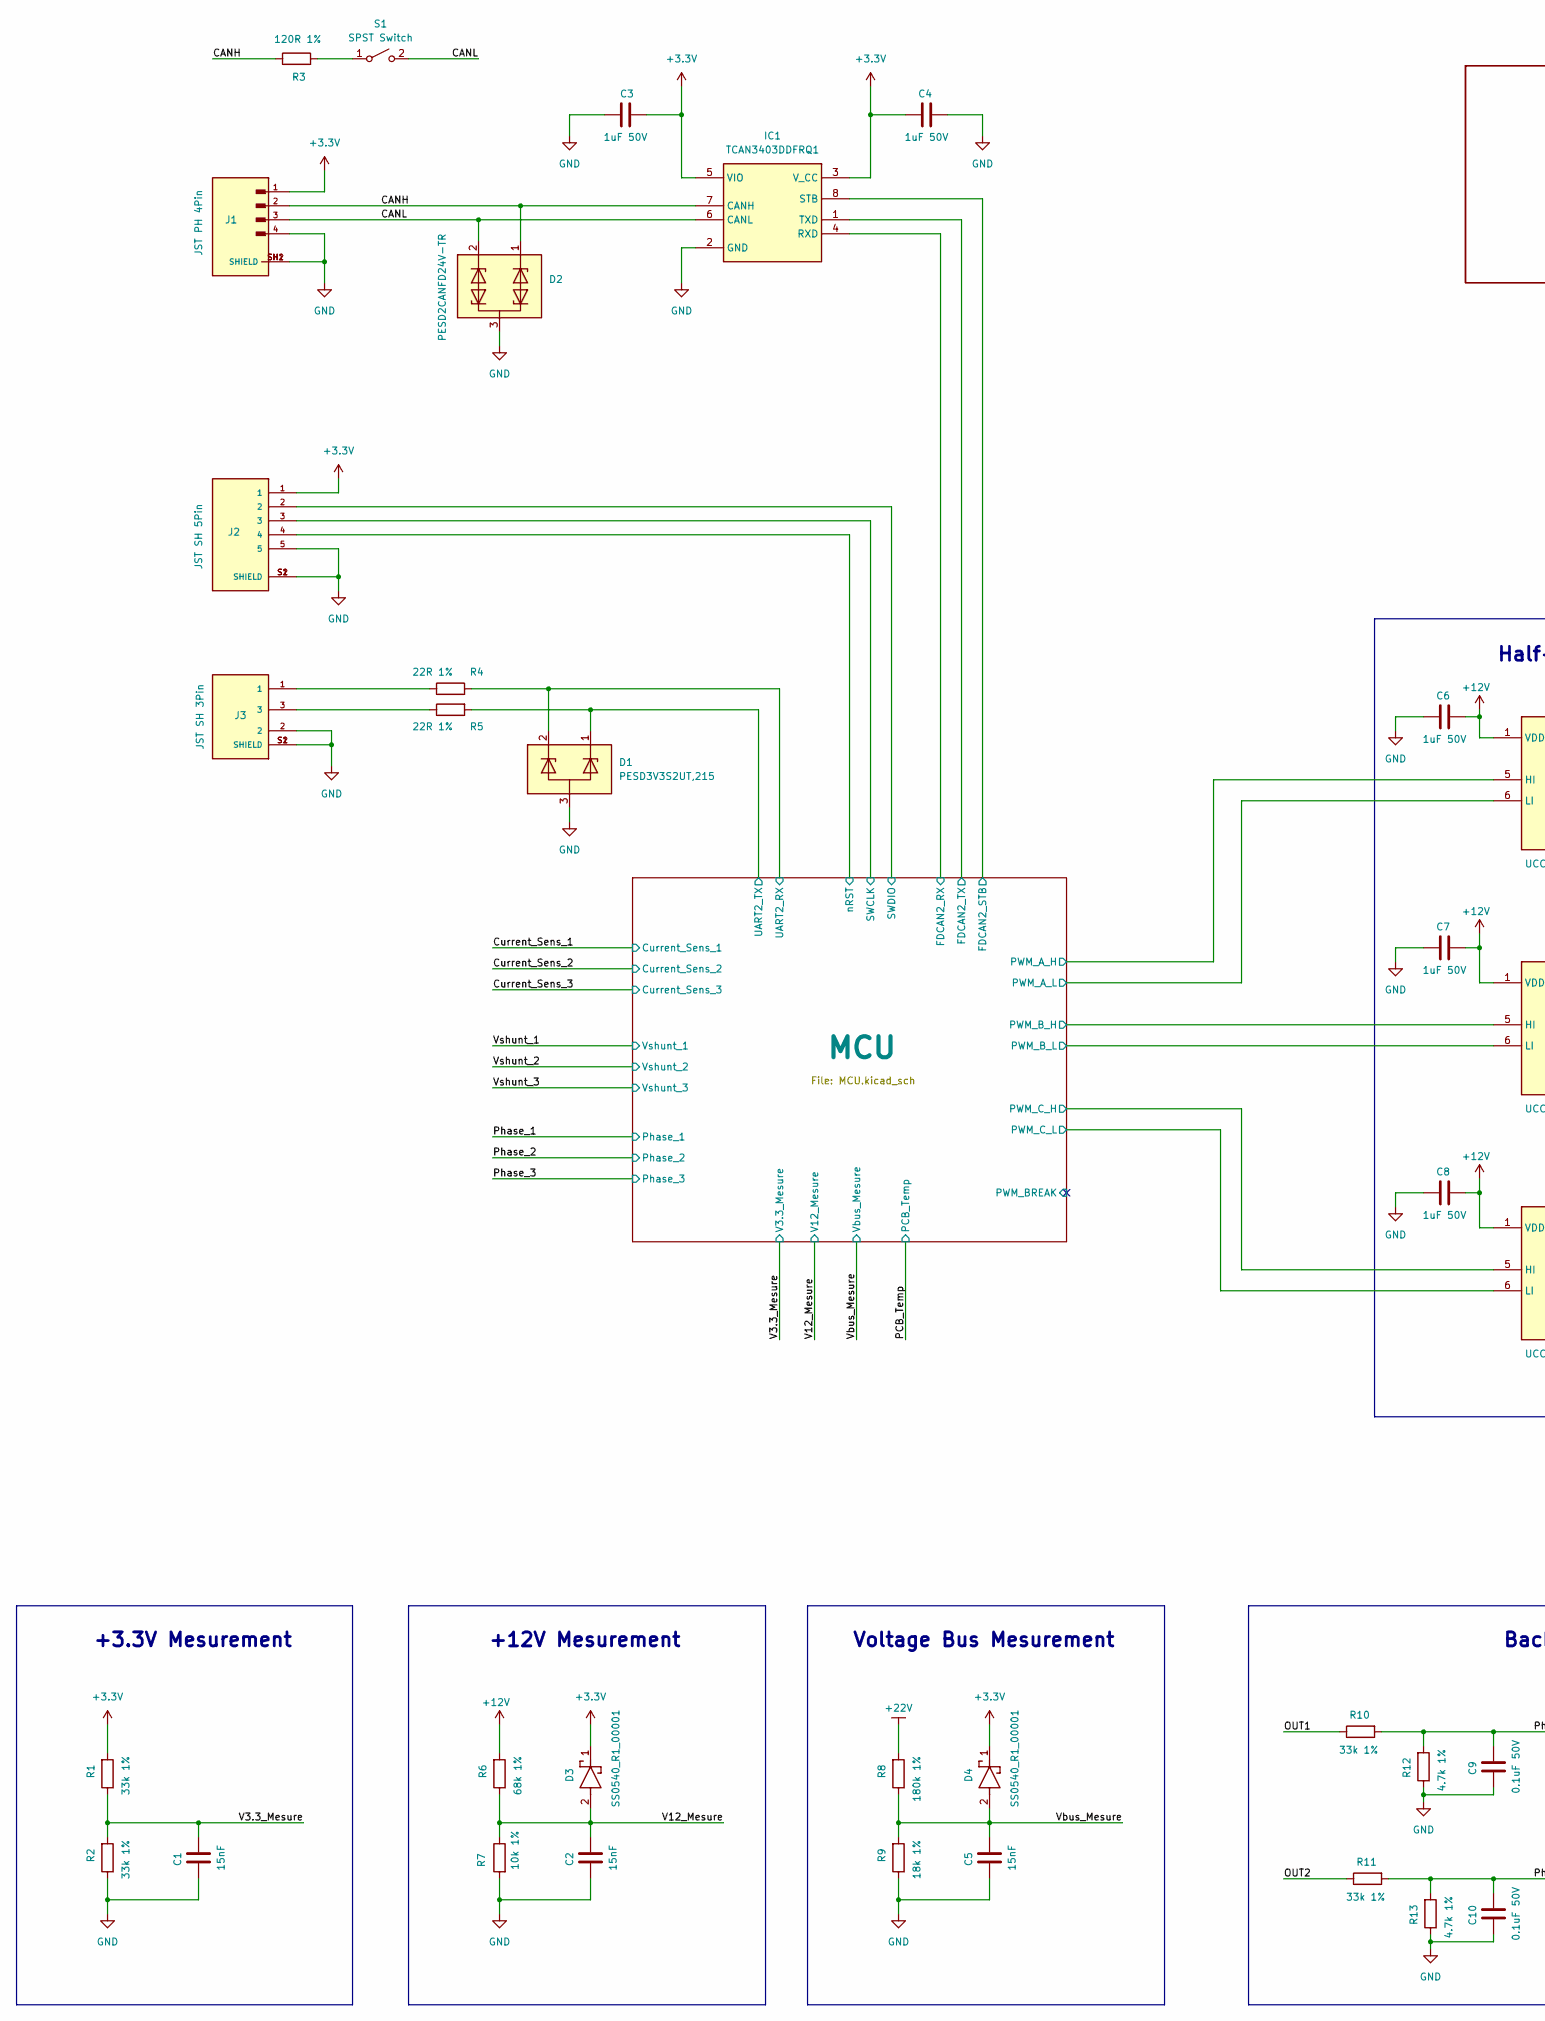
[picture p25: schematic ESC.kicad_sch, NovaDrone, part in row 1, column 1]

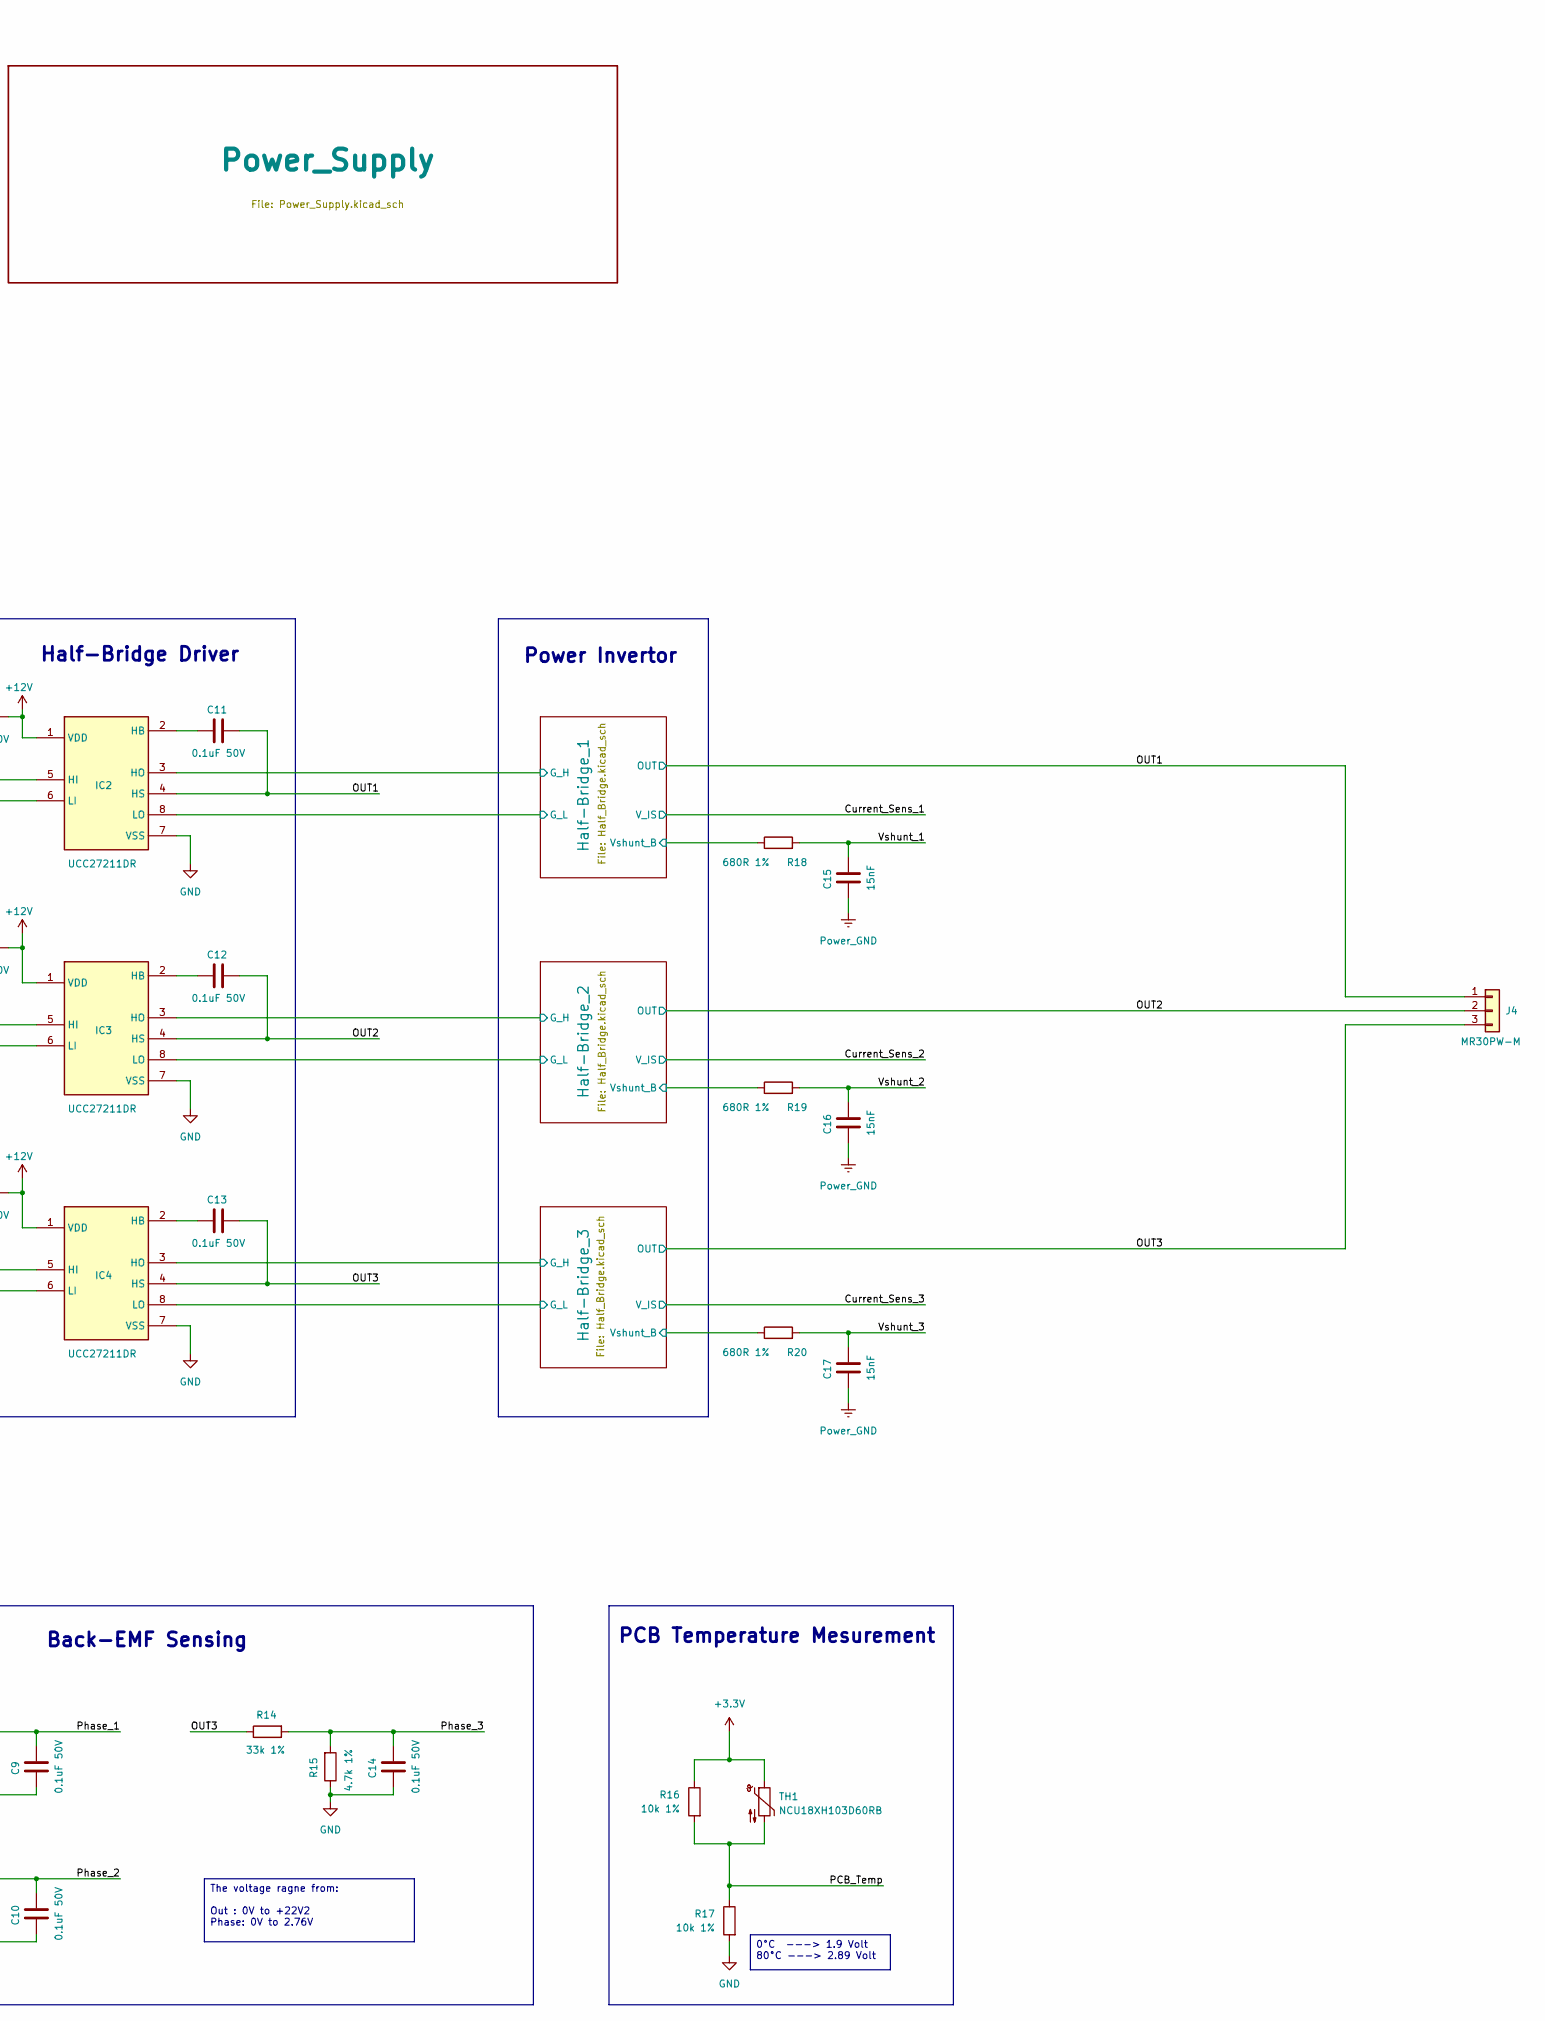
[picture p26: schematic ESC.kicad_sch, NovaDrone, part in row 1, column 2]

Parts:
C1, C2, C5, C15, C16, C17: 15nF; C_0603_1608Metric; Manufacturer_Part_Number CL10B153KB8NNNC
C3, C4, C6, C7, C8: 1uF 50V; C_0805_2012Metric; Manufacturer_Part_Number CL21B105KBFNNNE
C9, C10, C11, C12, C13, C14: 0.1uF 50V; C_0603_1608Metric; Manufacturer_Part_Number CL10B104KB85PNL
D1: PESD3V3S2UT,215; SOT95P230X110-3N; Mouser Part Number 771-PESD3V3S2UT-T/R
D2: PESD2CANFD24V-TR; SOT95P230X110-3N; Mouser Part Number 771-PESD2CANFD24V-TR
D3, D4: SS0540_R1_00001; SOD3816X135N; Mouser Part Number 241-SS0540_R1_00001
IC1: TCAN3403DDFRQ1; SOT65P280X110-8N; Mouser Part Number 595-TCAN3403DDFRQ1
IC2, IC3, IC4: UCC27211DR; SOIC127P600X175-8N; Mouser Part Number 595-UCC27211DR
J1: JST PH 4Pin; S4B-PH-SM4-TB; Manufacturer_Part_Number S4B-PH-SM4-TB(LF)(SN)
J2: JST SH 5Pin; JST_BM05B-SRSS-TB_LF__SN_; PARTREV N/A
J3: JST SH 3Pin; JST_BM03B-SRSS-TB_LF__SN_; PARTREV N/A
J4: MR30PW-M; AMASS_MR30PW-M_1x03_P3.50mm_Horizontal
R1, R2, R10, R11, R14: 33k 1%; R_0603_1608Metric; Manufacturer_Part_Number AC0603FR-1333KL
R3: 120R 1%; R_0603_1608Metric; Manufacturer_Part_Number AC0603FR-07120RL
R4: 22R 1%; R_0603_1608Metric; Manufacturer_Part_Number AC0603FR-0722RL
R5: 22R 1%; R_0603_1608Metric; Manufacturer_Part_Number RT0603FRD0722RL
R6: 68k 1%; R_0603_1608Metric; Manufacturer_Part_Number RC0603FR-1068KL
R7, R16, R17: 10k 1%; R_0603_1608Metric; Manufacturer_Part_Number AF0603FR-0710KL
R8: 180k 1%; R_0603_1608Metric; Manufacturer_Part_Number RT0603FRE07180KL
R9: 18k 1%; R_0603_1608Metric; Manufacturer_Part_Number AC0603FR-1318KL
R12, R13, R15: 4.7k 1%; R_0603_1608Metric; Manufacturer_Part_Number AF0603FR-074K7L
R18, R19, R20: 680R 1%; R_0603_1608Metric; Manufacturer_Part_Number RC0603FR-07680RL
S1: SPST Switch; DS04254201BKSMT; Mouser Part Number 490-DS04254201BK-SMT
TH1: NCU18XH103D60RB; R_0603_1608Metric; Manufacturer_Part_Number NCU18XH103D60RB

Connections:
+3.3V: C3.1, C4.1, D3.1 (K), D4.1 (K), IC1.3 (V_CC), IC1.5 (VIO), J1.1, J2.1, R1.2, R16.1, TH1.1; also elsewhere on the board
+12V: C6.2, C7.2, C8.2, IC2.1 (VDD), IC3.1 (VDD), IC4.1 (VDD), R6.2; also elsewhere on the board
+22V: R8.2; also elsewhere on the board
/CANH: D2.1, IC1.7 (CANH), J1.2, R3.1
/CANL: D2.2, IC1.6 (CANL), J1.3, S1.2
/Half-Bridge_1/G_H: IC2.3 (HO); also elsewhere on the board
/Half-Bridge_1/G_L: IC2.8 (LO); also elsewhere on the board
/Half-Bridge_1/Vshunt_B: R18.1; also elsewhere on the board
/Half-Bridge_2/G_H: IC3.3 (HO); also elsewhere on the board
/Half-Bridge_2/G_L: IC3.8 (LO); also elsewhere on the board
/Half-Bridge_2/Vshunt_B: R19.1; also elsewhere on the board
/Half-Bridge_3/G_H: IC4.3 (HO); also elsewhere on the board
/Half-Bridge_3/G_L: IC4.8 (LO); also elsewhere on the board
/Half-Bridge_3/Vshunt_B: R20.1; also elsewhere on the board
/MCU/FDCAN2_RX: IC1.4 (RXD); also elsewhere on the board
/MCU/FDCAN2_STB: IC1.8 (STB); also elsewhere on the board
/MCU/FDCAN2_TX: IC1.1 (TXD); also elsewhere on the board
/MCU/PWM_A_H: IC2.5 (HI); also elsewhere on the board
/MCU/PWM_A_L: IC2.6 (LI); also elsewhere on the board
/MCU/PWM_B_H: IC3.5 (HI); also elsewhere on the board
/MCU/PWM_B_L: IC3.6 (LI); also elsewhere on the board
/MCU/PWM_C_H: IC4.5 (HI); also elsewhere on the board
/MCU/PWM_C_L: IC4.6 (LI); also elsewhere on the board
/MCU/SWCLK: J2.3; also elsewhere on the board
/MCU/SWDIO: J2.2; also elsewhere on the board
/MCU/UART2_RX: D1.2, R4.2; also elsewhere on the board
/MCU/UART2_TX: D1.1, R5.2; also elsewhere on the board
/MCU/nRST: J2.4; also elsewhere on the board
/OUT1: C11.2, IC2.4 (HS), J4.1, R10.1; also elsewhere on the board
/OUT2: C12.2, IC3.4 (HS), J4.2, R11.1; also elsewhere on the board
/OUT3: C13.2, IC4.4 (HS), J4.3, R14.1; also elsewhere on the board
/PCB_Temp: R16.2, R17.1, TH1.2; also elsewhere on the board
/Phase_1: C9.2, R10.2, R12.2; also elsewhere on the board
/Phase_2: C10.2, R11.2, R13.2; also elsewhere on the board
/Phase_3: C14.2, R14.2, R15.2; also elsewhere on the board
/V3.3_Mesure: C1.2, R1.1, R2.2; also elsewhere on the board
/V12_Mesure: C2.2, D3.2 (A), R6.1, R7.1; also elsewhere on the board
/Vbus_Mesure: C5.2, D4.2 (A), R8.1, R9.2; also elsewhere on the board
/Vshunt_1: C15.2, R18.2; also elsewhere on the board
/Vshunt_2: C16.2, R19.2; also elsewhere on the board
/Vshunt_3: C17.2, R20.2; also elsewhere on the board
GND: C1.1, C2.1, C3.2, C4.2, C5.1, C6.1, C7.1, C8.1, C9.1, C10.1, C14.1, C15.1, C16.1, C17.1, D1.3, D2.3, IC1.2 (GND), IC2.7 (VSS), IC3.7 (VSS), IC4.7 (VSS), J1.4, J1.SH1 (SHIELD), J1.SH2 (SHIELD), J2.5, J2.S1 (SHIELD), J2.S2 (SHIELD), J3.2, J3.S1 (SHIELD), J3.S2 (SHIELD), R2.1, R7.2, R9.1, R12.1, R13.1, R15.1, R17.2; also elsewhere on the board
unnamed: C11.1, IC2.2 (HB)
unnamed: C12.1, IC3.2 (HB)
unnamed: C13.1, IC4.2 (HB)
unnamed: J3.1, R4.1
unnamed: J3.3, R5.1
unnamed: R3.2, S1.1

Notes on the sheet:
Voltage Bus Mesurement
Back-EMF Sensing
PCB Temperature Mesurement
Power Invertor
+3.3V Mesurement
+12V Mesurement
Half-Bridge Driver
0°C ---> 1.9 Volt 80°C ---> 2.89 Volt
The voltage ragne from: Out : 0V to +22V2 Phase: 0V to 2.76V

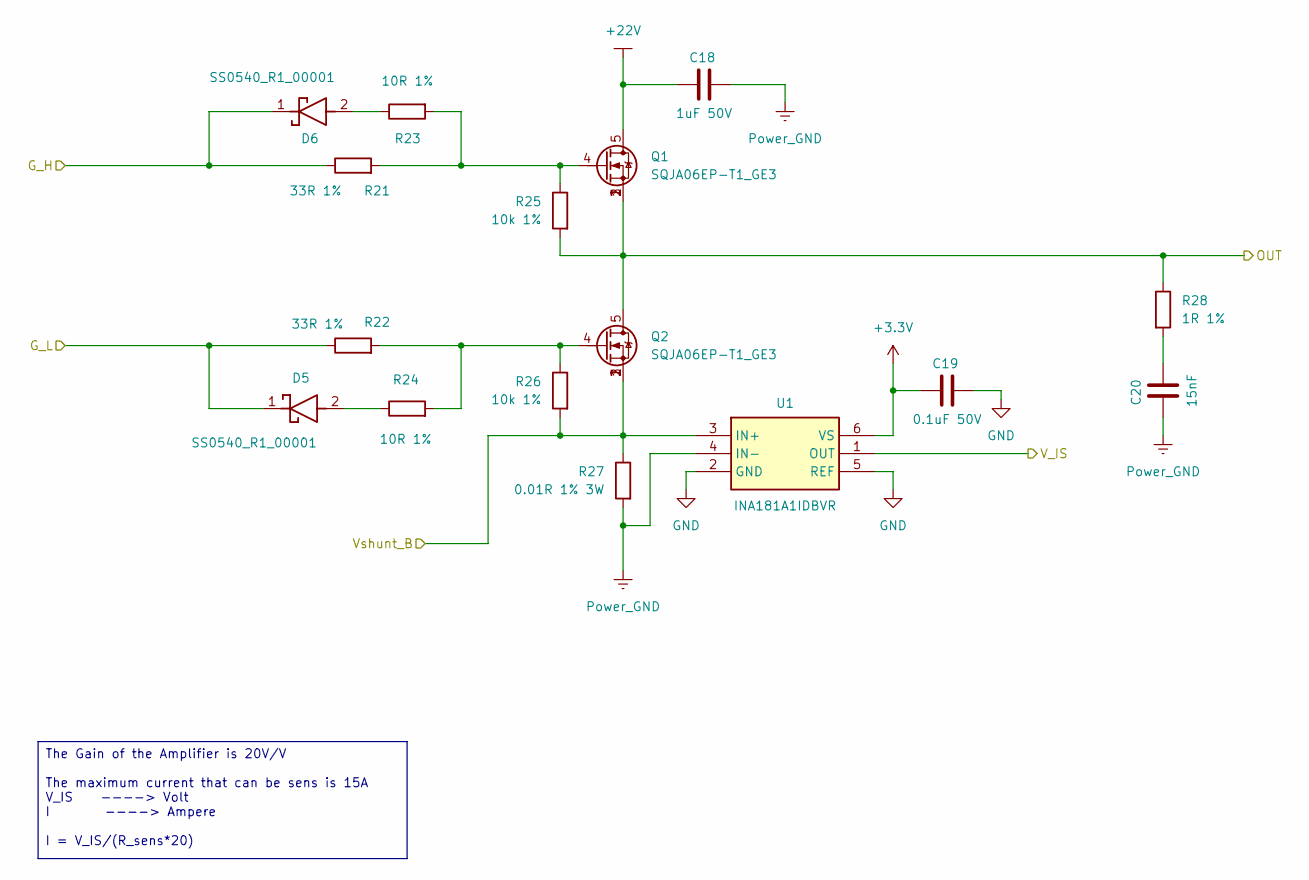
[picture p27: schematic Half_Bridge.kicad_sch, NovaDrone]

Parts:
C18: 1uF 50V; C_0805_2012Metric; Manufacturer_Part_Number CL21B105KBFNNNE
C19: 0.1uF 50V; C_0603_1608Metric; Manufacturer_Part_Number CL10B104KB85PNL
C20: 15nF; C_0603_1608Metric; Manufacturer_Part_Number CL10B153KB8NNNC
D5, D6: SS0540_R1_00001; SOD3816X135N; Mouser Part Number 241-SS0540_R1_00001
Q1, Q2: SQJA06EP-T1_GE3; PowerPAK_SO-8L_Single; Manufacturer_Part_Number SQJA06EP-T1_GE3
R21, R22: 33R 1%; R_0603_1608Metric; Manufacturer_Part_Number AF0603FR-0733RL
R23, R24: 10R 1%; R_0603_1608Metric; Manufacturer_Part_Number RE0603FRE0710RL
R25, R26: 10k 1%; R_0603_1608Metric; Manufacturer_Part_Number AF0603FR-0710KL
R27: 0.01R 1% 3W; R_2512_6332Metric; Manufacturer_Part_Number PA2512FKE7T0R01E
R28: 1R 1%; R_0603_1608Metric; Manufacturer_Part_Number AF0603FR-071RL
U1: INA181A1IDBVR; SOT95P280X145-6N; Mouser Part Number 595-INA181A1IDBVR

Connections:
+3.3V: C19.1, U1.6 (VS); also elsewhere on the board
+22V: C18.1, Q1.5; also elsewhere on the board
/Current_Sens_1: U1.1 (OUT); also elsewhere on the board
/Half-Bridge_1/G_H: D6.1 (K), R21.1; also elsewhere on the board
/Half-Bridge_1/G_L: D5.1 (K), R22.1; also elsewhere on the board
/Half-Bridge_1/Vshunt_B: Q2.1, Q2.2, Q2.3, R26.2, R27.1, U1.3 (IN+); also elsewhere on the board
/OUT1: Q1.1, Q1.2, Q1.3, Q2.5, R25.2, R28.1; also elsewhere on the board
GND: C18.2, C19.2, C20.1, R27.2, U1.2 (GND), U1.4 (IN-), U1.5 (REF); also elsewhere on the board
unnamed: C20.2, R28.2
unnamed: D5.2 (A), R24.1
unnamed: D6.2 (A), R23.1
unnamed: Q1.4, R21.2, R23.2, R25.1
unnamed: Q2.4, R22.2, R24.2, R26.1

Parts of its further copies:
C21, C24: 1uF 50V; C_0805_2012Metric; Manufacturer_Part_Number CL21B105KBFNNNE
C22, C25: 0.1uF 50V; C_0603_1608Metric; Manufacturer_Part_Number CL10B104KB85PNL
C23, C26: 15nF; C_0603_1608Metric; Manufacturer_Part_Number CL10B153KB8NNNC
D7, D8, D9, D10: SS0540_R1_00001; SOD3816X135N; Mouser Part Number 241-SS0540_R1_00001
Q3, Q4, Q5, Q6: SQJA06EP-T1_GE3; PowerPAK_SO-8L_Single; Manufacturer_Part_Number SQJA06EP-T1_GE3
R29, R30, R37, R38: 33R 1%; R_0603_1608Metric; Manufacturer_Part_Number AF0603FR-0733RL
R31, R32, R39, R40: 10R 1%; R_0603_1608Metric; Manufacturer_Part_Number RE0603FRE0710RL
R33, R34, R41, R42: 10k 1%; R_0603_1608Metric; Manufacturer_Part_Number AF0603FR-0710KL
R35, R43: 0.01R 1% 3W; R_2512_6332Metric; Manufacturer_Part_Number PA2512FKE7T0R01E
R36, R44: 1R 1%; R_0603_1608Metric; Manufacturer_Part_Number AF0603FR-071RL
U2, U3: INA181A1IDBVR; SOT95P280X145-6N; Mouser Part Number 595-INA181A1IDBVR

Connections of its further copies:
+3.3V: C22.1, C25.1, U2.6 (VS), U3.6 (VS); also elsewhere on the board
+22V: C21.1, C24.1, Q3.5, Q5.5; also elsewhere on the board
/Current_Sens_2: U3.1 (OUT); also elsewhere on the board
/Current_Sens_3: U2.1 (OUT); also elsewhere on the board
/Half-Bridge_2/G_H: D10.1 (K), R37.1; also elsewhere on the board
/Half-Bridge_2/G_L: D9.1 (K), R38.1; also elsewhere on the board
/Half-Bridge_2/Vshunt_B: Q6.1, Q6.2, Q6.3, R42.2, R43.1, U3.3 (IN+); also elsewhere on the board
/Half-Bridge_3/G_H: D8.1 (K), R29.1; also elsewhere on the board
/Half-Bridge_3/G_L: D7.1 (K), R30.1; also elsewhere on the board
/Half-Bridge_3/Vshunt_B: Q4.1, Q4.2, Q4.3, R34.2, R35.1, U2.3 (IN+); also elsewhere on the board
/OUT2: Q5.1, Q5.2, Q5.3, Q6.5, R41.2, R44.1; also elsewhere on the board
/OUT3: Q3.1, Q3.2, Q3.3, Q4.5, R33.2, R36.1; also elsewhere on the board
GND: C21.2, C22.2, C23.1, C24.2, C25.2, C26.1, R35.2, R43.2, U2.2 (GND), U2.4 (IN-), U2.5 (REF), U3.2 (GND), U3.4 (IN-), U3.5 (REF); also elsewhere on the board
unnamed: C23.2, R36.2
unnamed: C26.2, R44.2
unnamed: D7.2 (A), R32.1
unnamed: D8.2 (A), R31.1
unnamed: D9.2 (A), R40.1
unnamed: D10.2 (A), R39.1
unnamed: Q3.4, R29.2, R31.2, R33.1
unnamed: Q4.4, R30.2, R32.2, R34.1
unnamed: Q5.4, R37.2, R39.2, R41.1
unnamed: Q6.4, R38.2, R40.2, R42.1

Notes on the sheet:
The Gain of the Amplifier is 20V/V The maximum current that can be sens is 15A V_IS ----> Volt I ----> Ampere I = V_IS/(R_sens*20)

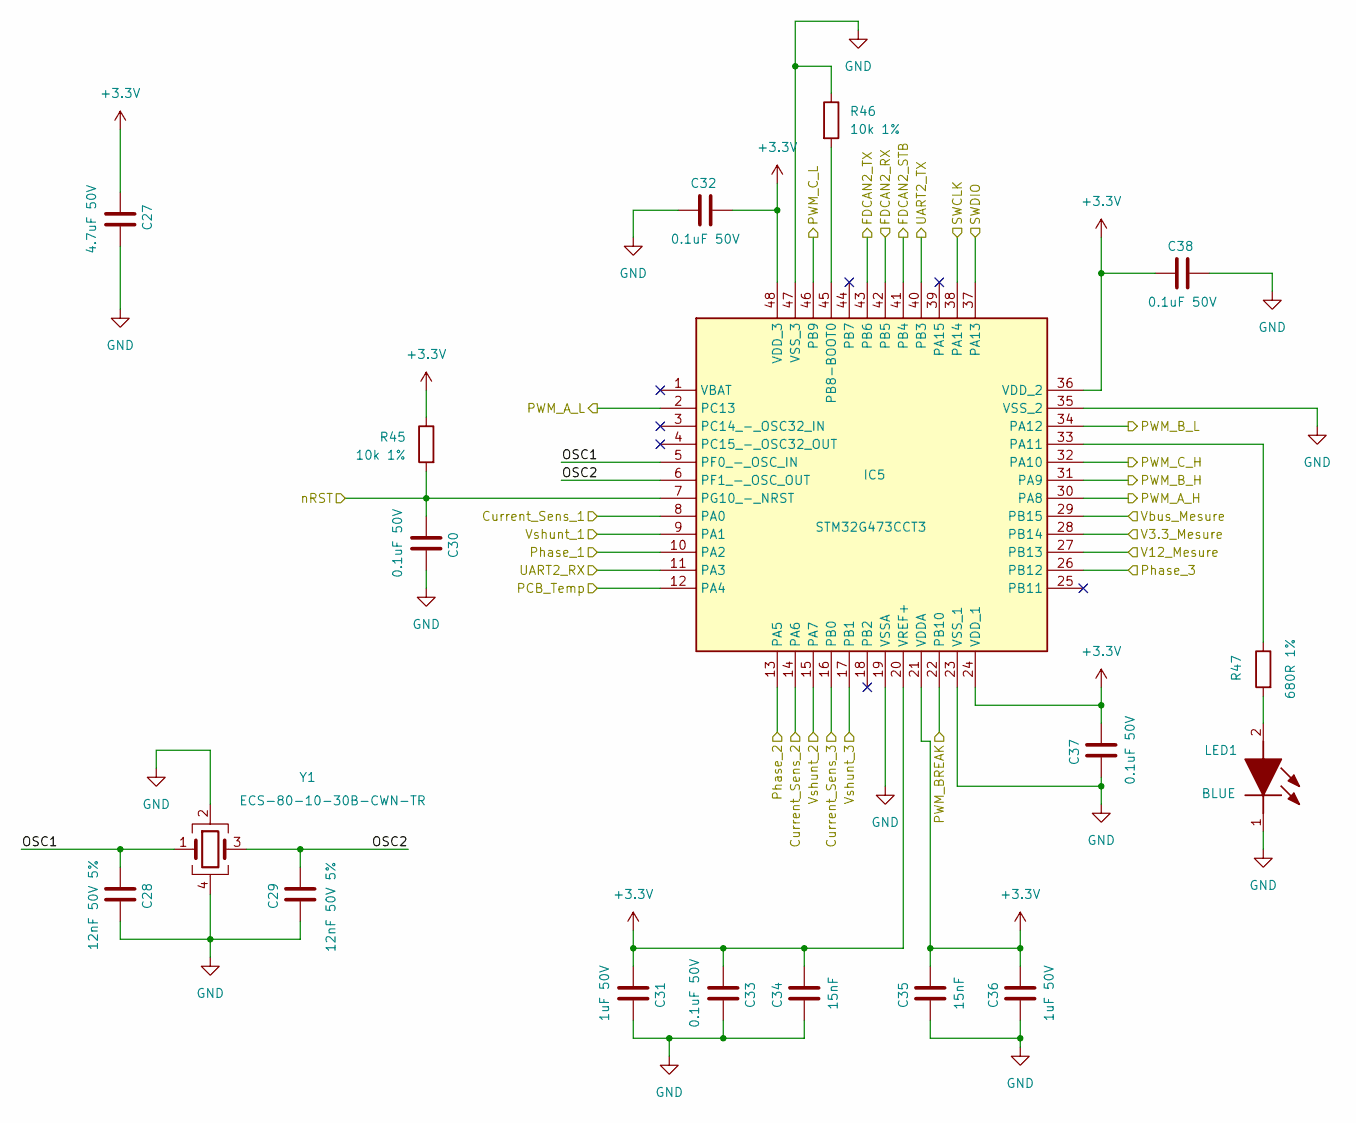
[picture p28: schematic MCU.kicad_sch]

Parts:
C27: 4.7uF 50V; C_1206_3216Metric; Manufacturer_Part_Number CL31B475KBHNFNE
C28, C29: 12nF 50V 5%; C_0603_1608Metric; Manufacturer_Part_Number 06035C120J4T2A
C30, C32, C33, C37, C38: 0.1uF 50V; C_0603_1608Metric; Manufacturer_Part_Number CL10B104KB85PNL
C31, C36: 1uF 50V; C_0805_2012Metric; Manufacturer_Part_Number CL21B105KBFNNNE
C34, C35: 15nF; C_0603_1608Metric; Manufacturer_Part_Number CL10B153KB8NNNC
IC5: STM32G473CCT3; QFP50P900X900X160-48N; Mouser Part Number 511-STM32G473CCT3
LED1: BLUE; LEDM168X80N; Mouser Part Number 604-APHD1608LQBCD
R45, R46: 10k 1%; R_0603_1608Metric; Manufacturer_Part_Number AF0603FR-0710KL
R47: 680R 1%; R_0603_1608Metric; Manufacturer_Part_Number RC0603FR-07680RL
Y1: ECS-80-10-30B-CWN-TR; ECS801830BAGNTR; Mouser Part Number 520-80-10-30B-CWNT

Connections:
+3.3V: C27.1, C31.2, C32.2, C33.2, C34.2, C35.2, C36.2, C37.2, C38.1, IC5.20 (VREF+), IC5.21 (VDDA), IC5.24 (VDD_1), IC5.36 (VDD_2), IC5.48 (VDD_3), R45.1; also elsewhere on the board
/Current_Sens_1: IC5.8 (PA0); also elsewhere on the board
/Current_Sens_2: IC5.14 (PA6); also elsewhere on the board
/Current_Sens_3: IC5.16 (PB0); also elsewhere on the board
/MCU/FDCAN2_RX: IC5.42 (PB5); also elsewhere on the board
/MCU/FDCAN2_STB: IC5.41 (PB4); also elsewhere on the board
/MCU/FDCAN2_TX: IC5.43 (PB6); also elsewhere on the board
/MCU/OSC1: C28.2, IC5.5 (PF0_-_OSC_IN), Y1.1
/MCU/OSC2: C29.2, IC5.6 (PF1_-_OSC_OUT), Y1.3
/MCU/PWM_A_H: IC5.30 (PA8); also elsewhere on the board
/MCU/PWM_A_L: IC5.2 (PC13); also elsewhere on the board
/MCU/PWM_BREAK: IC5.22 (PB10)
/MCU/PWM_B_H: IC5.31 (PA9); also elsewhere on the board
/MCU/PWM_B_L: IC5.34 (PA12); also elsewhere on the board
/MCU/PWM_C_H: IC5.32 (PA10); also elsewhere on the board
/MCU/PWM_C_L: IC5.46 (PB9); also elsewhere on the board
/MCU/SWCLK: IC5.38 (PA14); also elsewhere on the board
/MCU/SWDIO: IC5.37 (PA13); also elsewhere on the board
/MCU/UART2_RX: IC5.11 (PA3); also elsewhere on the board
/MCU/UART2_TX: IC5.40 (PB3); also elsewhere on the board
/MCU/nRST: C30.2, IC5.7 (PG10_-_NRST), R45.2; also elsewhere on the board
/PCB_Temp: IC5.12 (PA4); also elsewhere on the board
/Phase_1: IC5.10 (PA2); also elsewhere on the board
/Phase_2: IC5.13 (PA5); also elsewhere on the board
/Phase_3: IC5.26 (PB12); also elsewhere on the board
/V3.3_Mesure: IC5.28 (PB14); also elsewhere on the board
/V12_Mesure: IC5.27 (PB13); also elsewhere on the board
/Vbus_Mesure: IC5.29 (PB15); also elsewhere on the board
/Vshunt_1: IC5.9 (PA1); also elsewhere on the board
/Vshunt_2: IC5.15 (PA7); also elsewhere on the board
/Vshunt_3: IC5.17 (PB1); also elsewhere on the board
GND: C27.2, C28.1, C29.1, C30.1, C31.1, C32.1, C33.1, C34.1, C35.1, C36.1, C37.1, C38.2, IC5.19 (VSSA), IC5.23 (VSS_1), IC5.35 (VSS_2), IC5.47 (VSS_3), LED1.1 (K), R46.1, Y1.2, Y1.4; also elsewhere on the board
unnamed: IC5.33 (PA11), R47.1
unnamed: IC5.45 (PB8-BOOT0), R46.2
unnamed: LED1.2 (A), R47.2

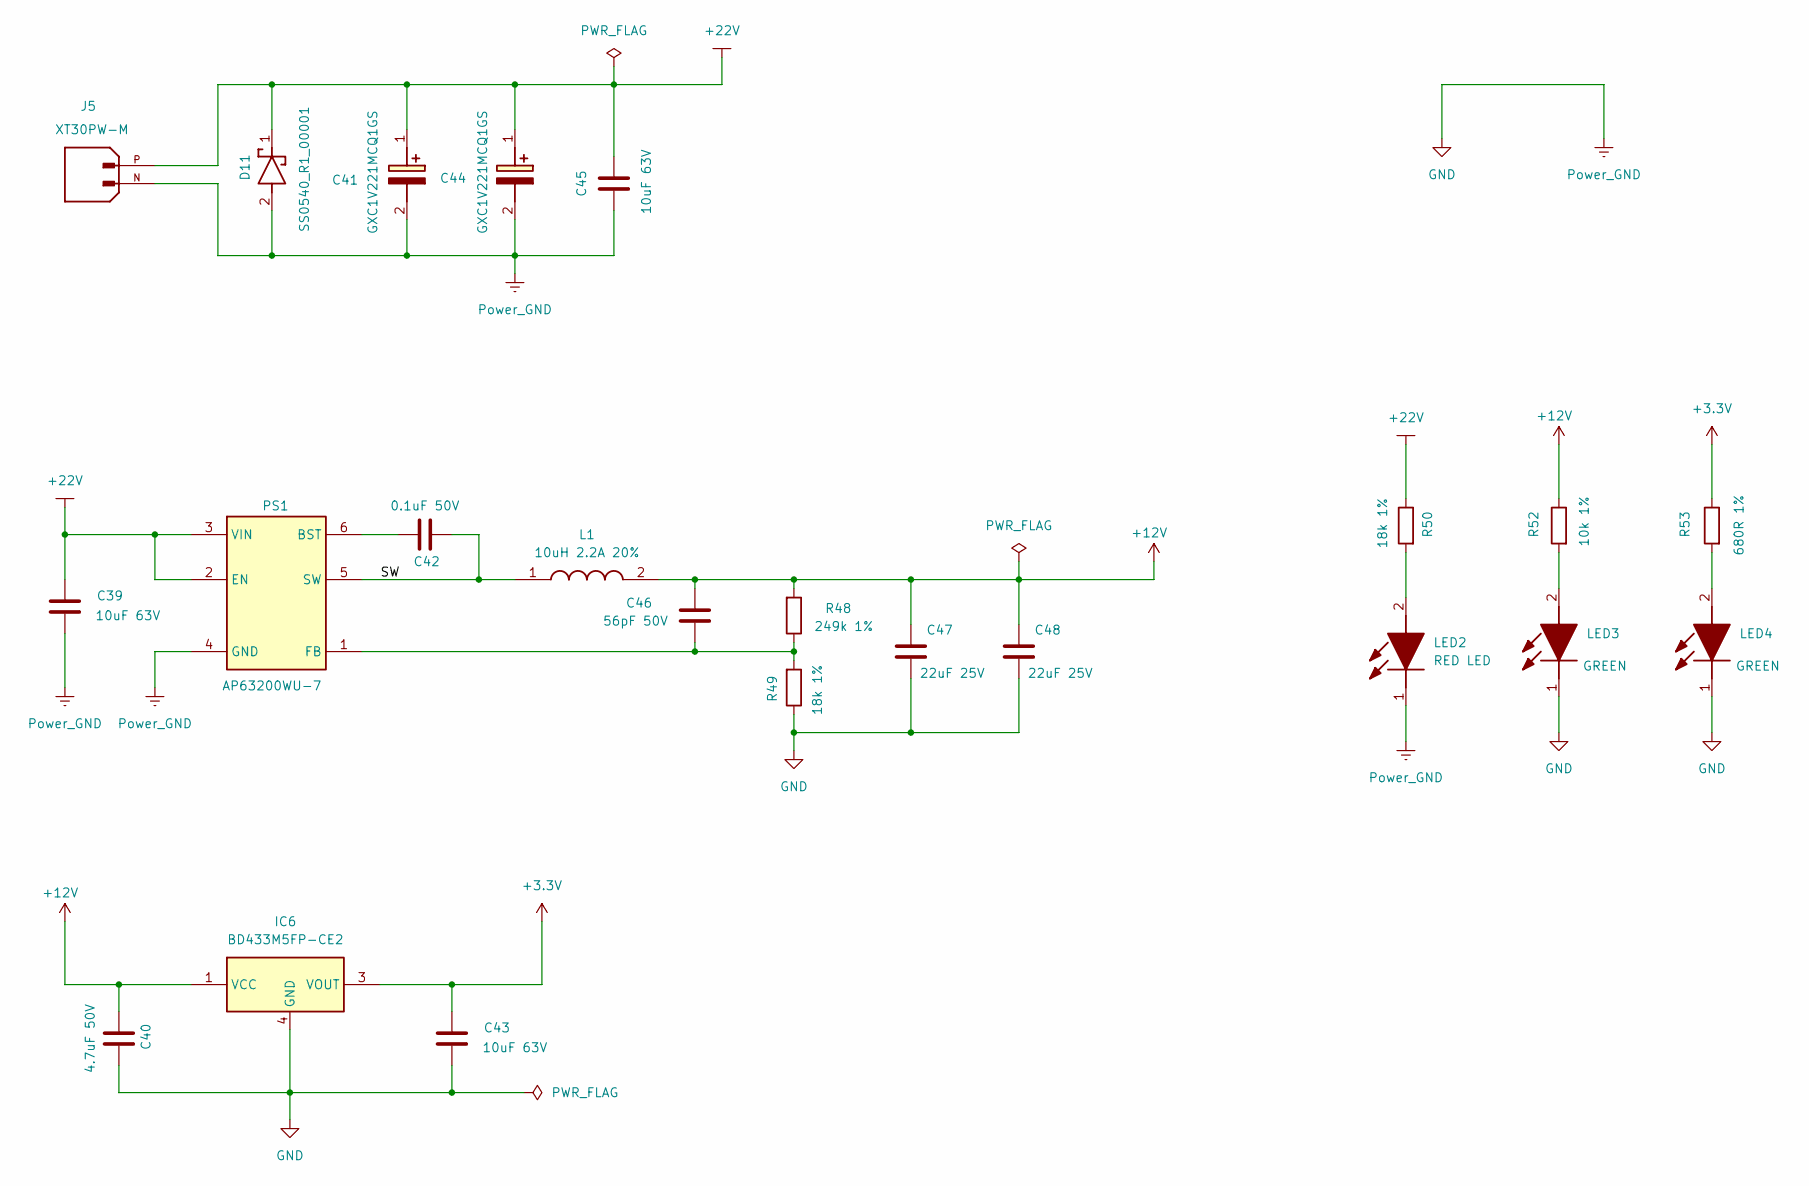
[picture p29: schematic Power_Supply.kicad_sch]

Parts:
C39, C43, C45: 10uF 63V; C_1210_3225Metric; Manufacturer_Part_Number CL32B106KMVNNWE
C40: 4.7uF 50V; C_1206_3216Metric; Manufacturer_Part_Number CL31B475KBHNFNE
C41, C44: GXC1V221MCQ1GS; CAPAE1030X1080N; Mouser Part Number 647-GXC1V221MCQ1GS
C42: 0.1uF 50V; C_0603_1608Metric; Manufacturer_Part_Number CL10B104KB85PNL
C46: 56pF 50V; C_0603_1608Metric; Manufacturer_Part_Number CL10C560JB8NNNC
C47, C48: 22uF 25V; C_1210_3225Metric; Manufacturer_Part_Number CL32B226KAJNNNE
D11: SS0540_R1_00001; SOD3816X135N; Mouser Part Number 241-SS0540_R1_00001
IC6: BD433M5FP-CE2; BD433M5FPCE2; Mouser Part Number 755-BD433M5FP-CE2
J5: XT30PW-M; AMASS_XT30PW-M; PARTREV 1.2
L1: 10uH 2.2A 20%; BWVS00505040100M00; Manufacturer_Part_Number BWVS00505040100M00
LED2: RED LED; LEDM168X80N; Manufacturer_Part_Number APHD1608LSURCK
LED3, LED4: GREEN; LEDM168X80N; Mouser Part Number 604-APHD1608LZGCK
PS1: AP63200WU-7; SOT95P280X100-6N; Mouser Part Number 621-AP63200WU-7
R48: 249k 1%; R_0603_1608Metric; Manufacturer_Part_Number AF0603FR-07249KL
R49, R50: 18k 1%; R_0603_1608Metric; Manufacturer_Part_Number AC0603FR-1318KL
R52: 10k 1%; R_0603_1608Metric; Manufacturer_Part_Number AF0603FR-0710KL
R53: 680R 1%; R_0603_1608Metric; Manufacturer_Part_Number RC0603FR-07680RL

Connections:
+3.3V: C43.2, IC6.3 (VOUT), R53.1; also elsewhere on the board
+12V: C40.1, C46.2, C47.2, C48.2, IC6.1 (VCC), L1.2, R48.2, R52.1; also elsewhere on the board
+22V: C39.2, C41.1 (+), C44.1 (+), C45.2, D11.1 (K), J5.P, PS1.2 (EN), PS1.3 (VIN), R50.1; also elsewhere on the board
/Power_Supply/SW: C42.1, L1.1, PS1.5 (SW)
GND: C39.1, C40.2, C41.2 (-), C43.1, C44.2 (-), C45.1, C47.1, C48.1, D11.2 (A), IC6.4 (GND), J5.N, LED2.1 (K), LED3.1 (K), LED4.1 (K), PS1.4 (GND), R49.1; also elsewhere on the board
unnamed: LED2.2 (A), R50.2
unnamed: LED3.2 (A), R52.2
unnamed: LED4.2 (A), R53.2
unnamed: C42.2, PS1.6 (BST)
unnamed: C46.1, PS1.1 (FB), R48.1, R49.2

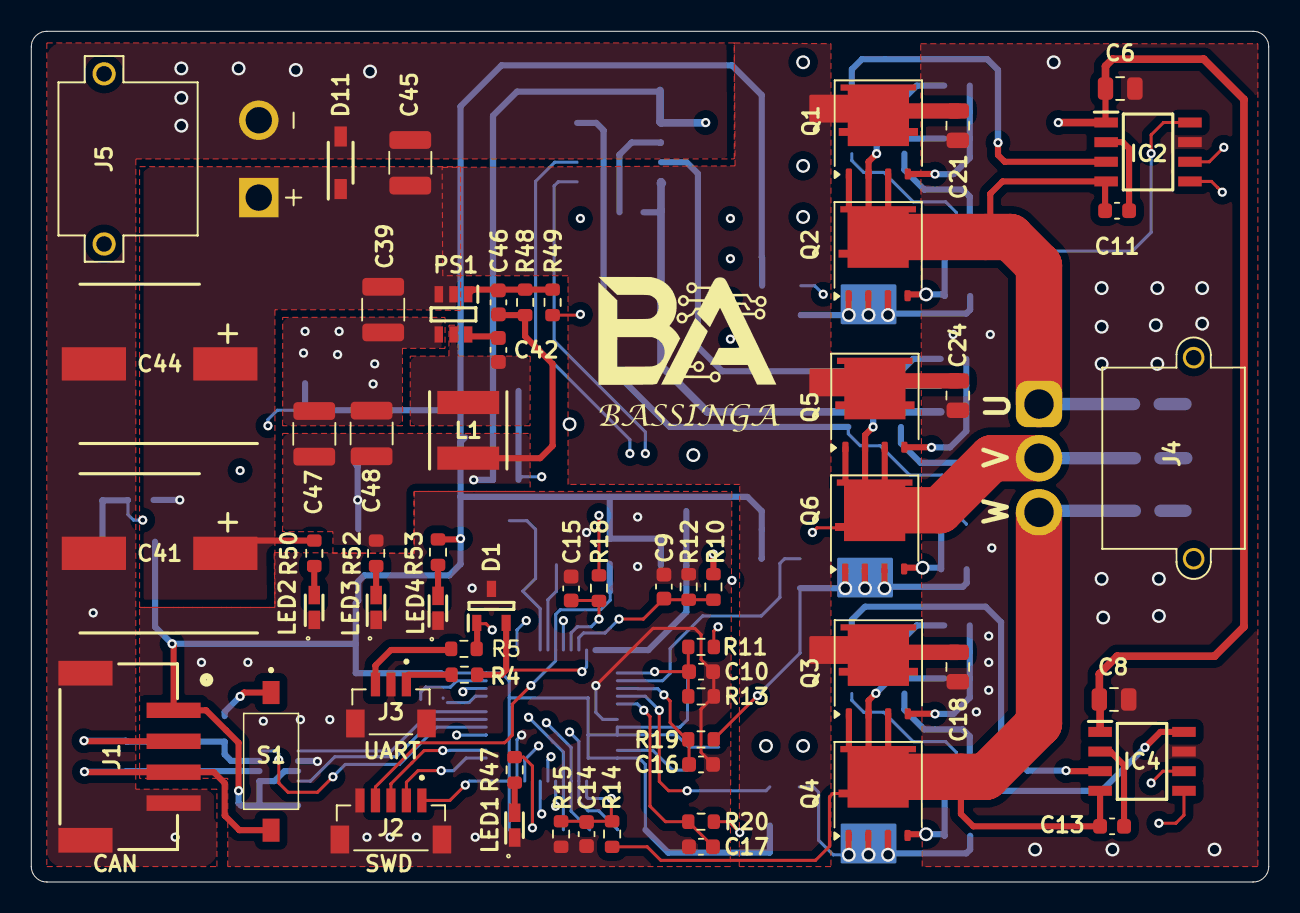
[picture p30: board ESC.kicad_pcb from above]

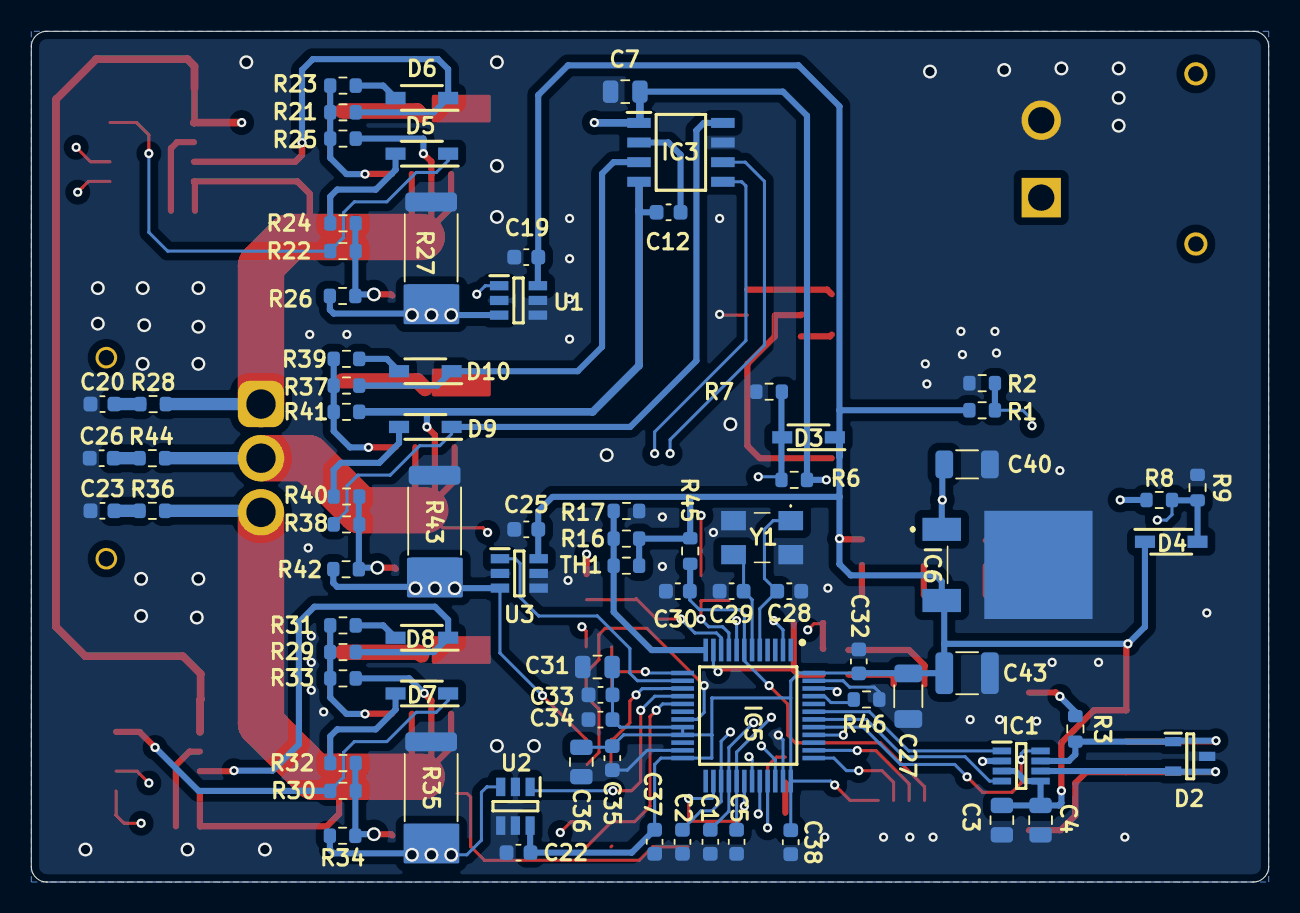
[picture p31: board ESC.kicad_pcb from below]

Board: 4 copper layers, 80.0 x 55.0 mm, 140 parts (80 on the bottom side), 77 nets.

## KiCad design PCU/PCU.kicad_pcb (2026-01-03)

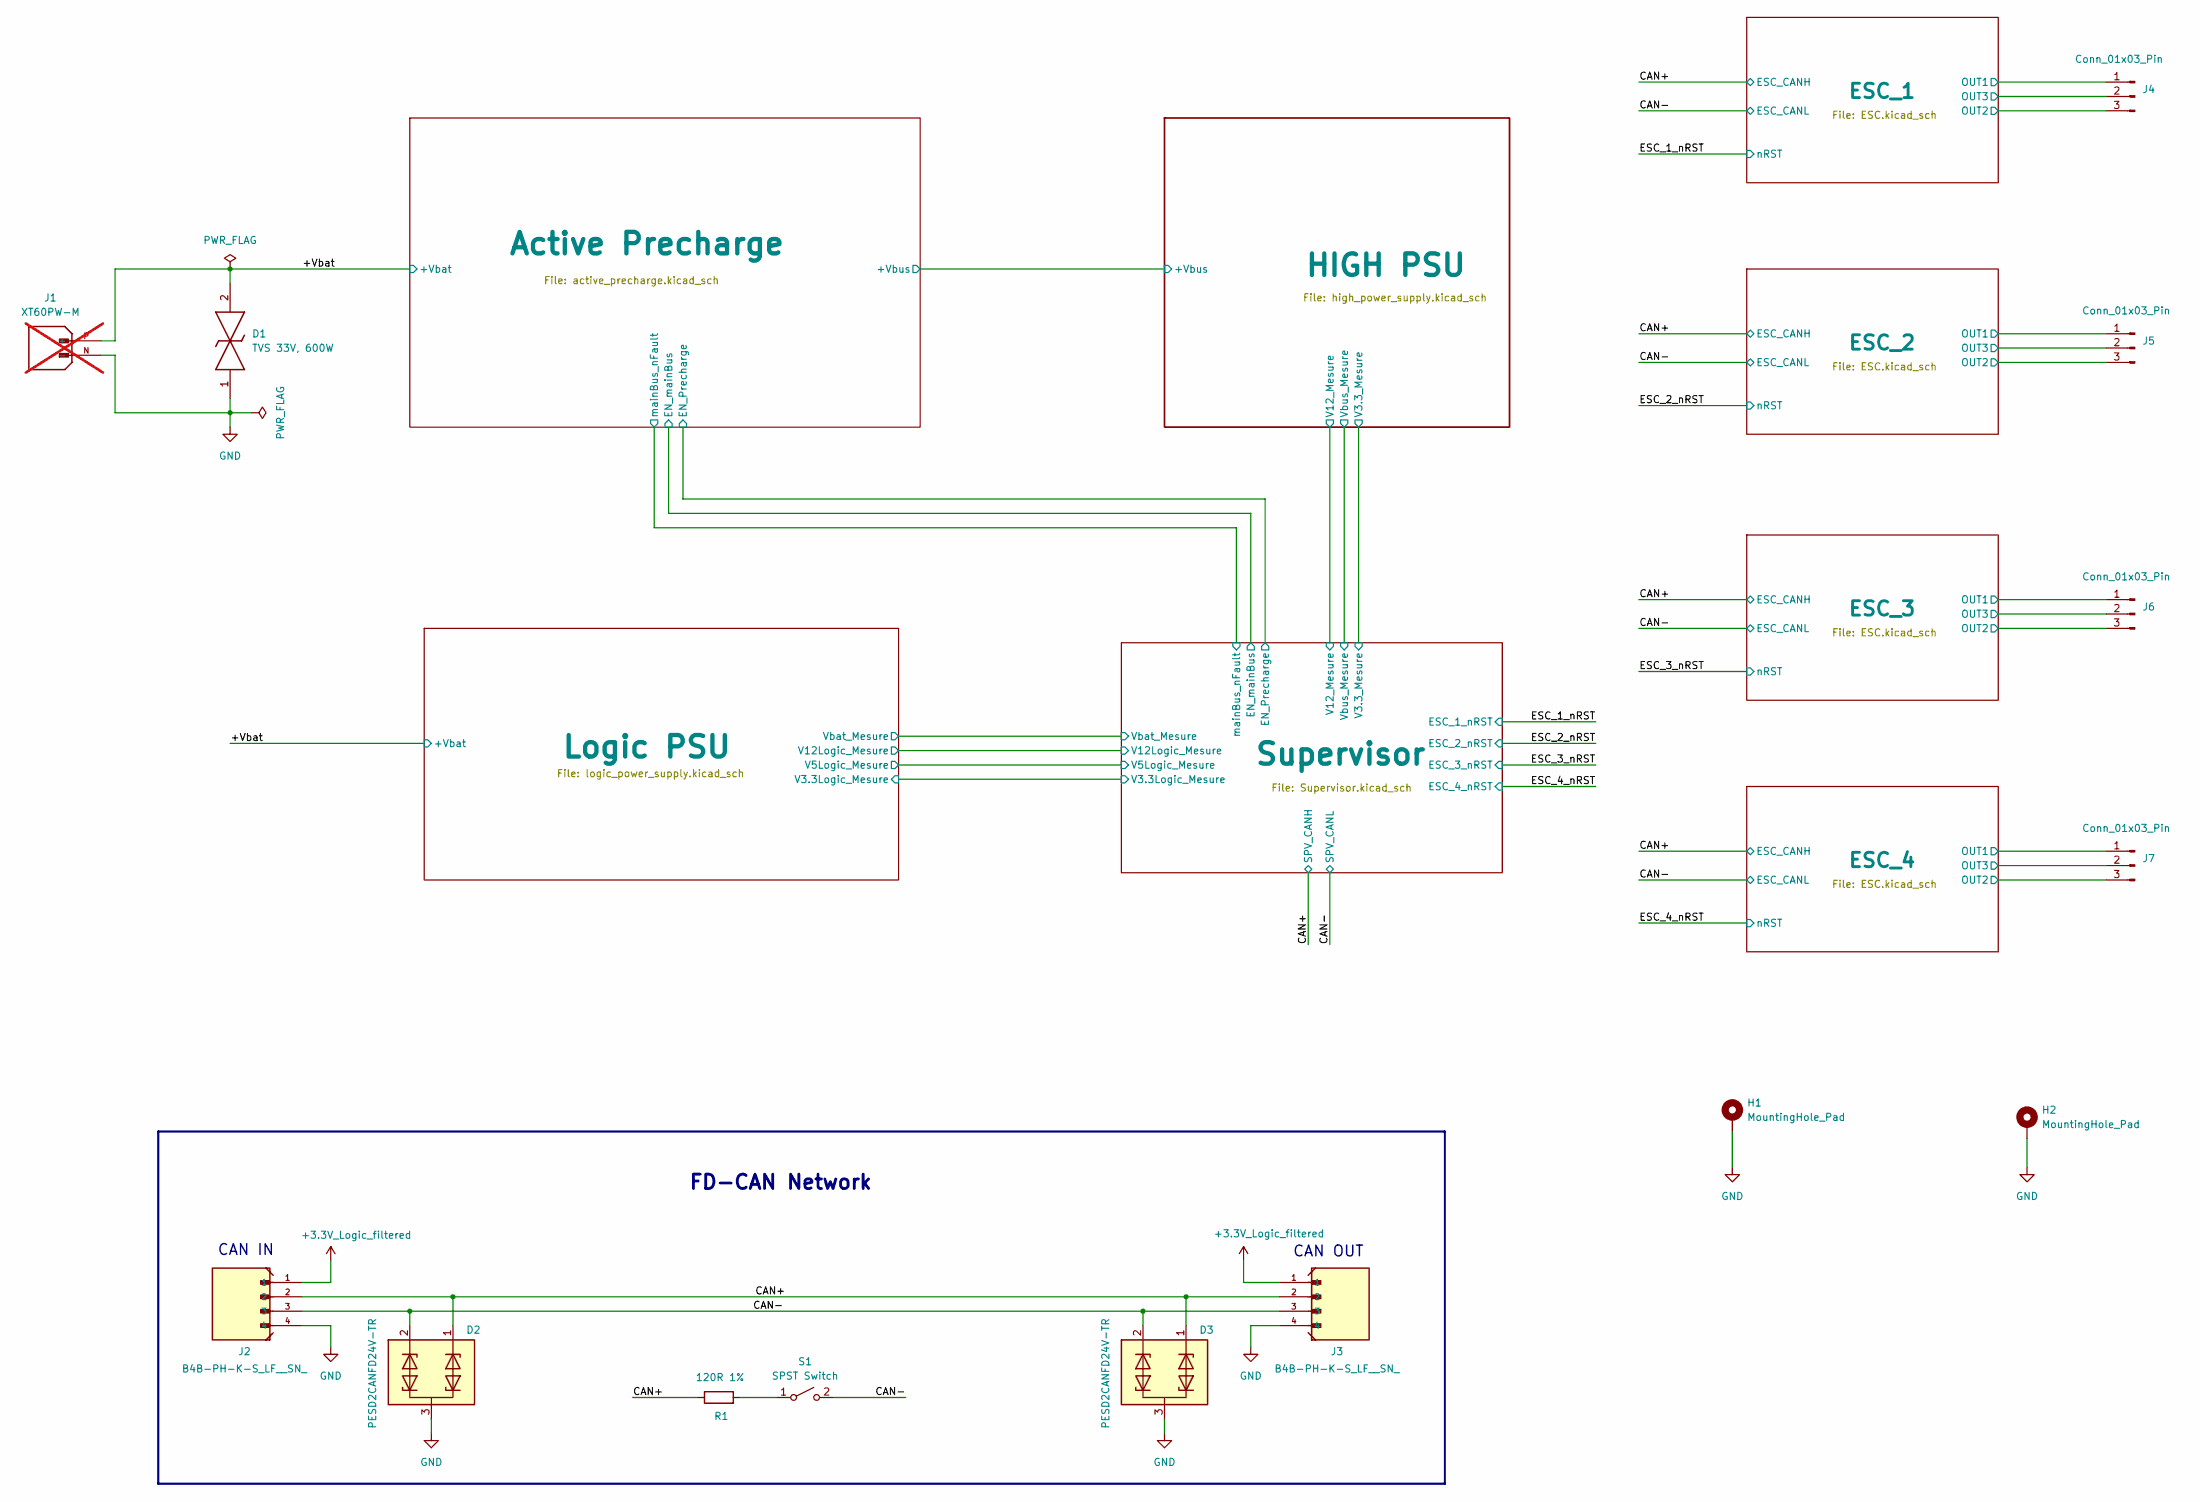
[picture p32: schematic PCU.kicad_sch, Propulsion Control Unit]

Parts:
D1: TVS 33V, 600W; DIONM5436X244N; Mouser Part Number 652-SMBJ33CA
D2, D3: PESD2CANFD24V-TR; SOT95P230X110-3N; Mouser Part Number 771-PESD2CANFD24V-TR
H1, H2: MountingHole_Pad; MountingHole_2.2mm_M2_DIN965_Pad
J1: XT60PW-M; AMASS_XT60PW-M; PARTREV V1.2; not fitted
J2, J3: B4B-PH-K-S_LF__SN_; JST_B4B-PH-K-S_LF__SN_
J4, J5, J6, J7: Conn_01x03_Pin; SolderWire-0.75sqmm_1x03_P4.8mm_D1.25mm_OD2.3mm
R1: 120R 1%; R_0603_1608Metric; Manufacturer_Part_Number AC0603FR-07120RL
S1: SPST Switch; DS04254201BKSMT; Mouser Part Number 490-DS04254201BK-SMT

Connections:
+3.3V_Logic_filtered: J2.1, J3.1; also elsewhere on the board
/+Vbat: D1.2, J1.P (+); also elsewhere on the board
/CAN+: D2.1, D3.1, J2.2, J3.2, R1.1; also elsewhere on the board
/CAN-: D2.2, D3.2, J2.3, J3.3, S1.2; also elsewhere on the board
/ESC_1/OUT1: J4.1; also elsewhere on the board
/ESC_1/OUT2: J4.3; also elsewhere on the board
/ESC_1/OUT3: J4.2; also elsewhere on the board
/ESC_2/OUT1: J5.1; also elsewhere on the board
/ESC_2/OUT2: J5.3; also elsewhere on the board
/ESC_2/OUT3: J5.2; also elsewhere on the board
/ESC_3/OUT1: J6.1; also elsewhere on the board
/ESC_3/OUT2: J6.3; also elsewhere on the board
/ESC_3/OUT3: J6.2; also elsewhere on the board
/ESC_4/OUT1: J7.1; also elsewhere on the board
/ESC_4/OUT2: J7.3; also elsewhere on the board
/ESC_4/OUT3: J7.2; also elsewhere on the board
GND: D1.1, D2.3, D3.3, H1.1, H2.1, J1.N (-), J2.4, J3.4; also elsewhere on the board
unnamed: R1.2, S1.1

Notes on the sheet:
CAN IN
FD-CAN Network
CAN OUT

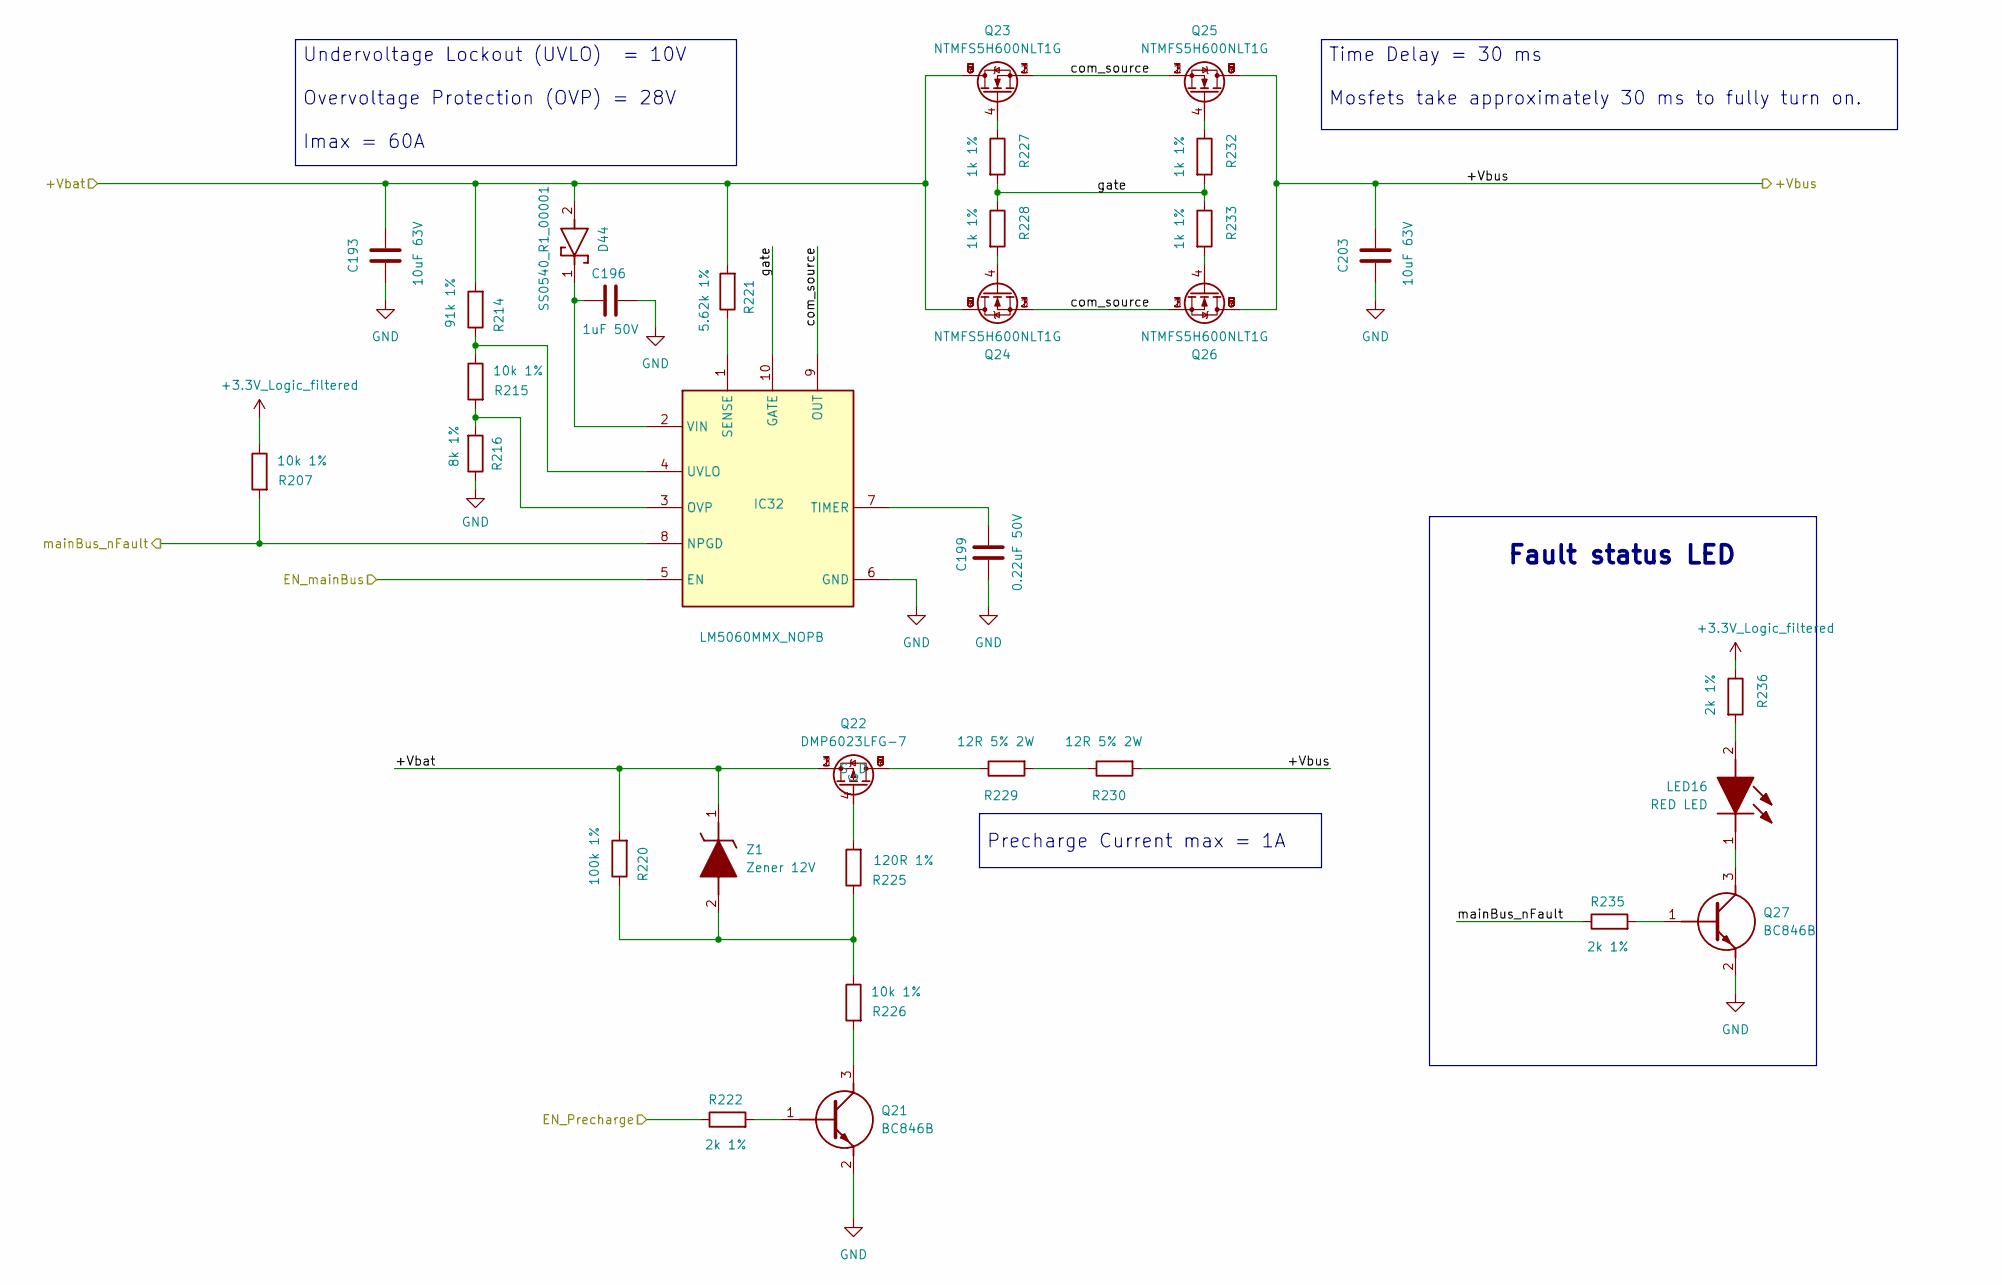
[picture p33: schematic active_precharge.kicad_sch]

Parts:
C193, C203: 10uF 63V; C_1210_3225Metric; Manufacturer_Part_Number CL32B106KMVNNWE
C196: 1uF 50V; C_0805_2012Metric; Manufacturer_Part_Number CL21B105KBFNNNE
C199: 0.22uF 50V; C_0603_1608Metric; Manufacturer_Part_Number CL10B224KB8NNNC
D44: SS0540_R1_00001; SOD3816X135N; Mouser Part Number 241-SS0540_R1_00001
IC32: LM5060MMX_NOPB; SOP50P490X110-10N; Mouser Part Number 926-LM5060MMX/NOPB
LED16: RED LED; LEDM168X80N; Manufacturer_Part_Number APHD1608LSURCK
Q21, Q27: BC846B; SOT95P230X110-3N; Mouser Part Number 637-BC846B
Q22: DMP6023LFG-7; DMP4013LFG7; Mouser Part Number 621-DMP6023LFG-7
Q23, Q24, Q25, Q26: NTMFS5H600NLT1G; Mouser Part Number 863-NTMFS5H600NLT1G
R207, R215, R226: 10k 1%; R_0603_1608Metric; Manufacturer_Part_Number AF0603FR-0710KL
R214: 91k 1%; R_0603_1608Metric; Manufacturer_Part_Number RT0603BRD0791KL
R216: 8k 1%; R_0603_1608Metric; Manufacturer_Part_Number RT0603BRE078KL
R220: 100k 1%; R_0603_1608Metric; Manufacturer_Part_Number AT0603FRE07100KL
R221: 5.62k 1%; R_0603_1608Metric; Manufacturer_Part_Number RC0603FR-135K62L
R222, R235, R236: 2k 1%; R_0603_1608Metric; Manufacturer_Part_Number RE0603FRE072KL
R225: 120R 1%; R_0603_1608Metric; Manufacturer_Part_Number AC0603FR-07120RL
R227, R228, R232, R233: 1k 1%; R_0603_1608Metric; Manufacturer_Part_Number RT0603FRE071KL
R229, R230: 12R 5% 2W; R_2512_6332Metric; Manufacturer_Part_Number CRGH2512J12R
Z1: Zener 12V; SOD3716X135N; Mouser Part Number 863-MMSZ12T1G

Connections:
+3.3V_Logic_filtered: R207.1, R236.1; also elsewhere on the board
+Vbus: C203.2, Q25.5, Q25.6, Q25.7, Q25.8, Q25.9, Q26.5, Q26.6, Q26.7, Q26.8, Q26.9, R230.2; also elsewhere on the board
/+Vbat: C193.2, D44.2 (A), Q22.1 (S), Q22.2 (S), Q22.3 (S), Q23.5, Q23.6, Q23.7, Q23.8, Q23.9, Q24.5, Q24.6, Q24.7, Q24.8, Q24.9, R214.2, R220.2, R221.2, Z1.1 (K); also elsewhere on the board
/Active Precharge/EN_Precharge: R222.1; also elsewhere on the board
/Active Precharge/EN_mainBus: IC32.5 (EN); also elsewhere on the board
/Active Precharge/com_source: IC32.9 (OUT), Q23.1, Q23.2, Q23.3, Q24.1, Q24.2, Q24.3, Q25.1, Q25.2, Q25.3, Q26.1, Q26.2, Q26.3
/Active Precharge/gate: IC32.10 (GATE), R227.2, R228.1, R232.2, R233.1
/Active Precharge/mainBus_nFault: IC32.8 (NPGD), R207.2, R235.1; also elsewhere on the board
GND: C193.1, C196.2, C199.1, C203.1, IC32.6 (GND), Q21.2 (E), Q27.2 (E), R216.1; also elsewhere on the board
unnamed: C196.1, D44.1 (K), IC32.2 (VIN)
unnamed: IC32.3 (OVP), R215.2, R216.2
unnamed: IC32.1 (SENSE), R221.1
unnamed: C199.2, IC32.7 (TIMER)
unnamed: IC32.4 (UVLO), R214.1, R215.1
unnamed: LED16.2 (A), R236.2
unnamed: LED16.1 (K), Q27.3 (C)
unnamed: Q21.1 (B), R222.2
unnamed: Q21.3 (C), R226.2
unnamed: Q22.5 (D), Q22.6 (D), Q22.7 (D), Q22.8 (D), Q22.9 (D), R229.1
unnamed: Q22.4 (G), R225.2
unnamed: Q23.4, R227.1
unnamed: Q24.4, R228.2
unnamed: Q25.4, R232.1
unnamed: Q26.4, R233.2
unnamed: Q27.1 (B), R235.2
unnamed: R229.2, R230.1
unnamed: R220.1, R225.1, R226.1, Z1.2 (A)

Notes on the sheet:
Fault status LED
Precharge Current max = 1A
Undervoltage Lockout (UVLO) = 10V Overvoltage Protection (OVP) = 28V Imax = 60A
Time Delay = 30 ms Mosfets take approximately 30 ms to fully turn on.

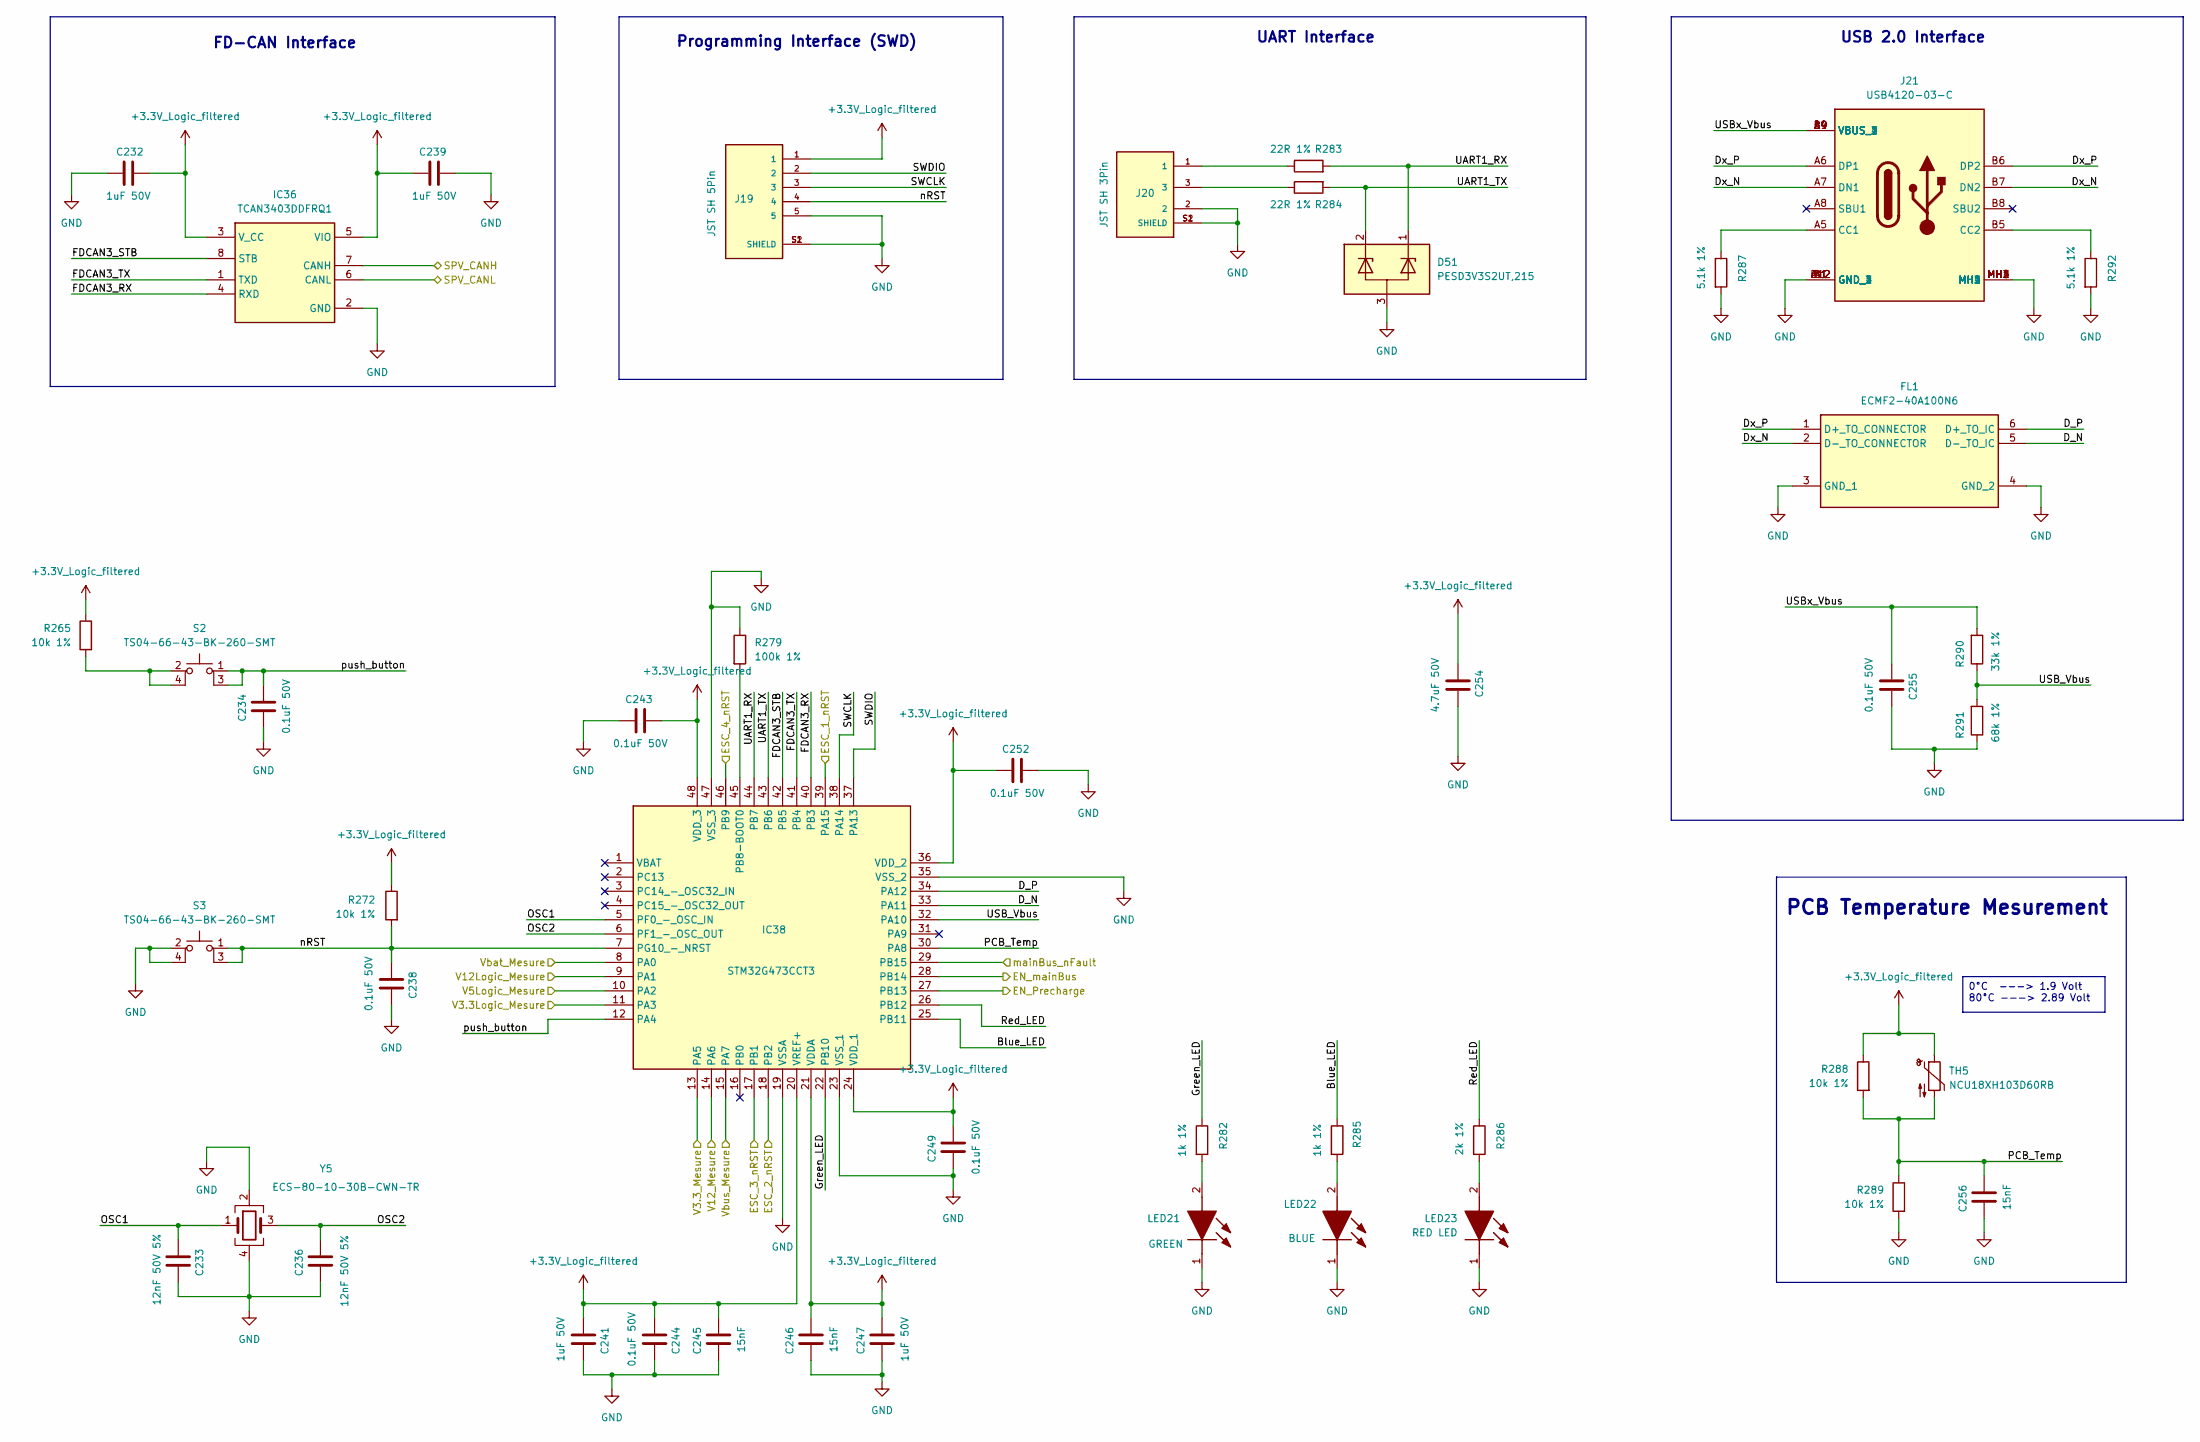
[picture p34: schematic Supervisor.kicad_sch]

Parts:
C232, C239, C241, C247: 1uF 50V; C_0805_2012Metric; Manufacturer_Part_Number CL21B105KBFNNNE
C233, C236: 12nF 50V 5%; C_0603_1608Metric; Manufacturer_Part_Number 06035C120J4T2A
C234, C238, C243, C244, C249, C252, C255: 0.1uF 50V; C_0603_1608Metric; Manufacturer_Part_Number CL10B104KB85PNL
C245, C246, C256: 15nF; C_0603_1608Metric; Manufacturer_Part_Number CL10B153KB8NNNC
C254: 4.7uF 50V; C_1206_3216Metric; Manufacturer_Part_Number CL31B475KBHNFNE
D51: PESD3V3S2UT,215; SOT95P230X110-3N; Mouser Part Number 771-PESD3V3S2UT-T/R
FL1: ECMF2-40A100N6; ECMF240A100N6; Mouser Part Number 511-ECMF2-40A100N6
IC36: TCAN3403DDFRQ1; SOT65P280X110-8N; Mouser Part Number 595-TCAN3403DDFRQ1
IC38: STM32G473CCT3; QFP50P900X900X160-48N; Mouser Part Number 511-STM32G473CCT3
J19: JST SH 5Pin; JST_BM05B-SRSS-TB_LF__SN_; PARTREV N/A
J20: JST SH 3Pin; JST_BM03B-SRSS-TB_LF__SN_; PARTREV N/A
J21: USB4120-03-C; USB412003C; Mouser Part Number 640-USB4120-03-C
LED21: GREEN; LEDM168X80N; Mouser Part Number 604-APHD1608LZGCK
LED22: BLUE; LEDM168X80N; Mouser Part Number 604-APHD1608LQBCD
LED23: RED LED; LEDM168X80N; Manufacturer_Part_Number APHD1608LSURCK
R265, R272, R288, R289: 10k 1%; R_0603_1608Metric; Manufacturer_Part_Number AF0603FR-0710KL
R279: 100k 1%; R_0603_1608Metric; Manufacturer_Part_Number AT0603FRE07100KL
R282, R285: 1k 1%; R_0603_1608Metric; Manufacturer_Part_Number RT0603FRE071KL
R283, R284: 22R 1%; R_0603_1608Metric; Manufacturer_Part_Number RT0603FRD0722RL
R286: 2k 1%; R_0603_1608Metric; Manufacturer_Part_Number RE0603FRE072KL
R287, R292: 5.1k 1%; R_0603_1608Metric; Manufacturer_Part_Number RC0603FR-075K1P
R290: 33k 1%; R_0603_1608Metric; Manufacturer_Part_Number AC0603FR-1333KL
R291: 68k 1%; R_0603_1608Metric; Manufacturer_Part_Number RC0603FR-1068KL
S2, S3: TS04-66-43-BK-260-SMT; TS046643BK260SMT; Mouser Part Number 179-TS046643BK260SMT
TH5: NCU18XH103D60RB; R_0603_1608Metric; Manufacturer_Part_Number NCU18XH103D60RB
Y5: ECS-80-10-30B-CWN-TR; ECS801830BAGNTR; Mouser Part Number 520-80-10-30B-CWNT

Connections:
+3.3V_Logic_filtered: C232.1, C239.1, C241.2, C243.2, C244.2, C245.2, C246.2, C247.2, C249.2, C252.1, C254.1, IC36.3 (V_CC), IC36.5 (VIO), IC38.20 (VREF+), IC38.21 (VDDA), IC38.24 (VDD_1), IC38.36 (VDD_2), IC38.48 (VDD_3), J19.1, R265.1, R272.1, R288.1, TH5.1; also elsewhere on the board
/Active Precharge/EN_Precharge: IC38.27 (PB13); also elsewhere on the board
/Active Precharge/EN_mainBus: IC38.28 (PB14); also elsewhere on the board
/Active Precharge/mainBus_nFault: IC38.29 (PB15); also elsewhere on the board
/CAN+: IC36.7 (CANH); also elsewhere on the board
/CAN-: IC36.6 (CANL); also elsewhere on the board
/ESC_1_nRST: IC38.39 (PA15); also elsewhere on the board
/ESC_2_nRST: IC38.18 (PB2); also elsewhere on the board
/ESC_3_nRST: IC38.17 (PB1); also elsewhere on the board
/ESC_4_nRST: IC38.46 (PB9); also elsewhere on the board
/HIGH PSU/V3.3_Mesure: IC38.13 (PA5); also elsewhere on the board
/HIGH PSU/V12_Mesure: IC38.14 (PA6); also elsewhere on the board
/HIGH PSU/Vbus_Mesure: IC38.15 (PA7); also elsewhere on the board
/Logic PSU/V3.3Logic_Mesure: IC38.11 (PA3); also elsewhere on the board
/Logic PSU/V5Logic_Mesure: IC38.10 (PA2); also elsewhere on the board
/Logic PSU/V12Logic_Mesure: IC38.9 (PA1); also elsewhere on the board
/Logic PSU/Vbat_Mesure: IC38.8 (PA0); also elsewhere on the board
/Supervisor/Blue_LED: IC38.25 (PB11), R285.1
/Supervisor/D_N: FL1.5 (D-_TO_IC), IC38.33 (PA11)
/Supervisor/D_P: FL1.6 (D+_TO_IC), IC38.34 (PA12)
/Supervisor/Dx_N: FL1.2 (D-_TO_CONNECTOR), J21.A7 (DN1), J21.B7 (DN2)
/Supervisor/Dx_P: FL1.1 (D+_TO_CONNECTOR), J21.A6 (DP1), J21.B6 (DP2)
/Supervisor/FDCAN3_RX: IC36.4 (RXD), IC38.40 (PB3)
/Supervisor/FDCAN3_STB: IC36.8 (STB), IC38.42 (PB5)
/Supervisor/FDCAN3_TX: IC36.1 (TXD), IC38.41 (PB4)
/Supervisor/Green_LED: IC38.22 (PB10), R282.1
/Supervisor/OSC1: C233.2, IC38.5 (PF0_-_OSC_IN), Y5.1
/Supervisor/OSC2: C236.2, IC38.6 (PF1_-_OSC_OUT), Y5.3
/Supervisor/PCB_Temp: C256.2, IC38.30 (PA8), R288.2, R289.1, TH5.2
/Supervisor/Red_LED: IC38.26 (PB12), R286.1
/Supervisor/SWCLK: IC38.38 (PA14), J19.3
/Supervisor/SWDIO: IC38.37 (PA13), J19.2
/Supervisor/UART1_RX: D51.1, IC38.44 (PB7), R283.2
/Supervisor/UART1_TX: D51.2, IC38.43 (PB6), R284.2
/Supervisor/USB_Vbus: IC38.32 (PA10), R290.1, R291.2
/Supervisor/USBx_Vbus: C255.2, J21.A4 (VBUS_1), J21.A9 (VBUS_2), J21.B4 (VBUS_3), J21.B9 (VBUS_4), R290.2
/Supervisor/nRST: C238.2, IC38.7 (PG10_-_NRST), J19.4, R272.2, S3.1, S3.3
/Supervisor/push_button: C234.2, IC38.12 (PA4), S2.1, S2.3
GND: C232.2, C233.1, C234.1, C236.1, C238.1, C239.2, C241.1, C243.1, C244.1, C245.1, C246.1, C247.1, C249.1, C252.2, C254.2, C255.1, C256.1, D51.3, FL1.3 (GND_1), FL1.4 (GND_2), IC36.2 (GND), IC38.19 (VSSA), IC38.23 (VSS_1), IC38.35 (VSS_2), IC38.47 (VSS_3), J19.5, J19.S1 (SHIELD), J19.S2 (SHIELD), J20.2, J20.S1 (SHIELD), J20.S2 (SHIELD), J21.A1 (GND_1), J21.A12 (GND_2), J21.B1 (GND_3), J21.B12 (GND_4), J21.MH1, J21.MH2, J21.MH3, J21.MH4, LED21.1 (K), LED22.1 (K), LED23.1 (K), R279.1, R287.2, R289.2, R291.1, R292.2, S3.2, S3.4, Y5.2, Y5.4; also elsewhere on the board
unnamed: IC38.45 (PB8-BOOT0), R279.2
unnamed: J20.1, R283.1
unnamed: J20.3, R284.1
unnamed: J21.A5 (CC1), R287.1
unnamed: J21.B5 (CC2), R292.1
unnamed: LED21.2 (A), R282.2
unnamed: LED22.2 (A), R285.2
unnamed: LED23.2 (A), R286.2
unnamed: R265.2, S2.2, S2.4

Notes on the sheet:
Programming Interface (SWD)
USB 2.0 Interface
FD-CAN Interface
UART Interface
PCB Temperature Mesurement
0°C ---> 1.9 Volt 80°C ---> 2.89 Volt

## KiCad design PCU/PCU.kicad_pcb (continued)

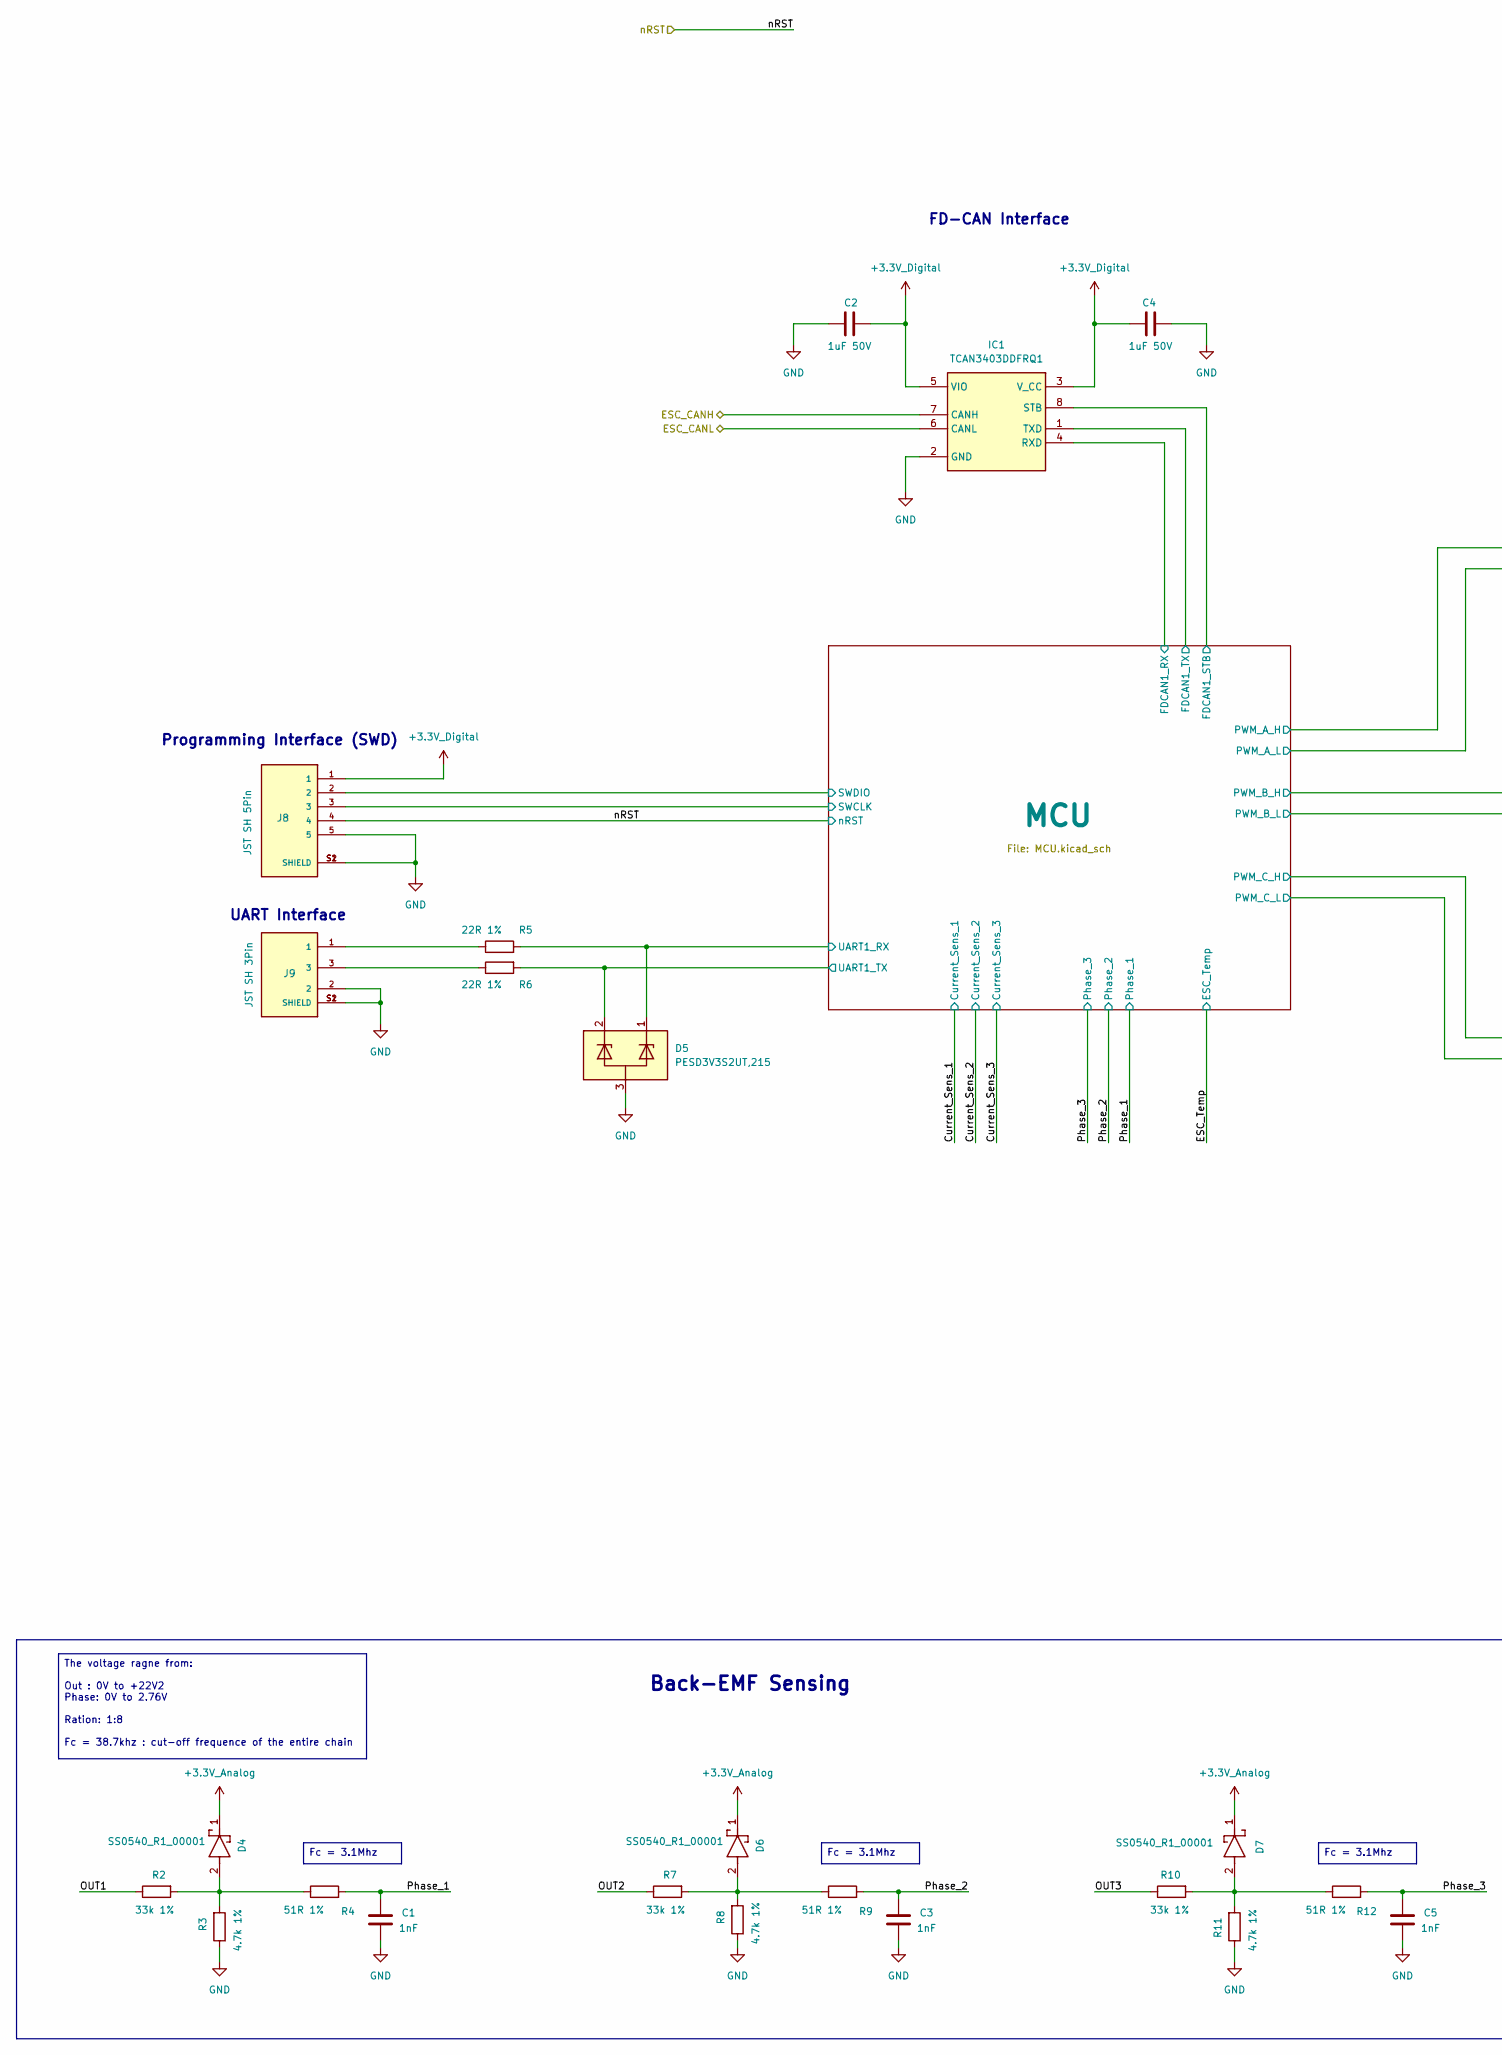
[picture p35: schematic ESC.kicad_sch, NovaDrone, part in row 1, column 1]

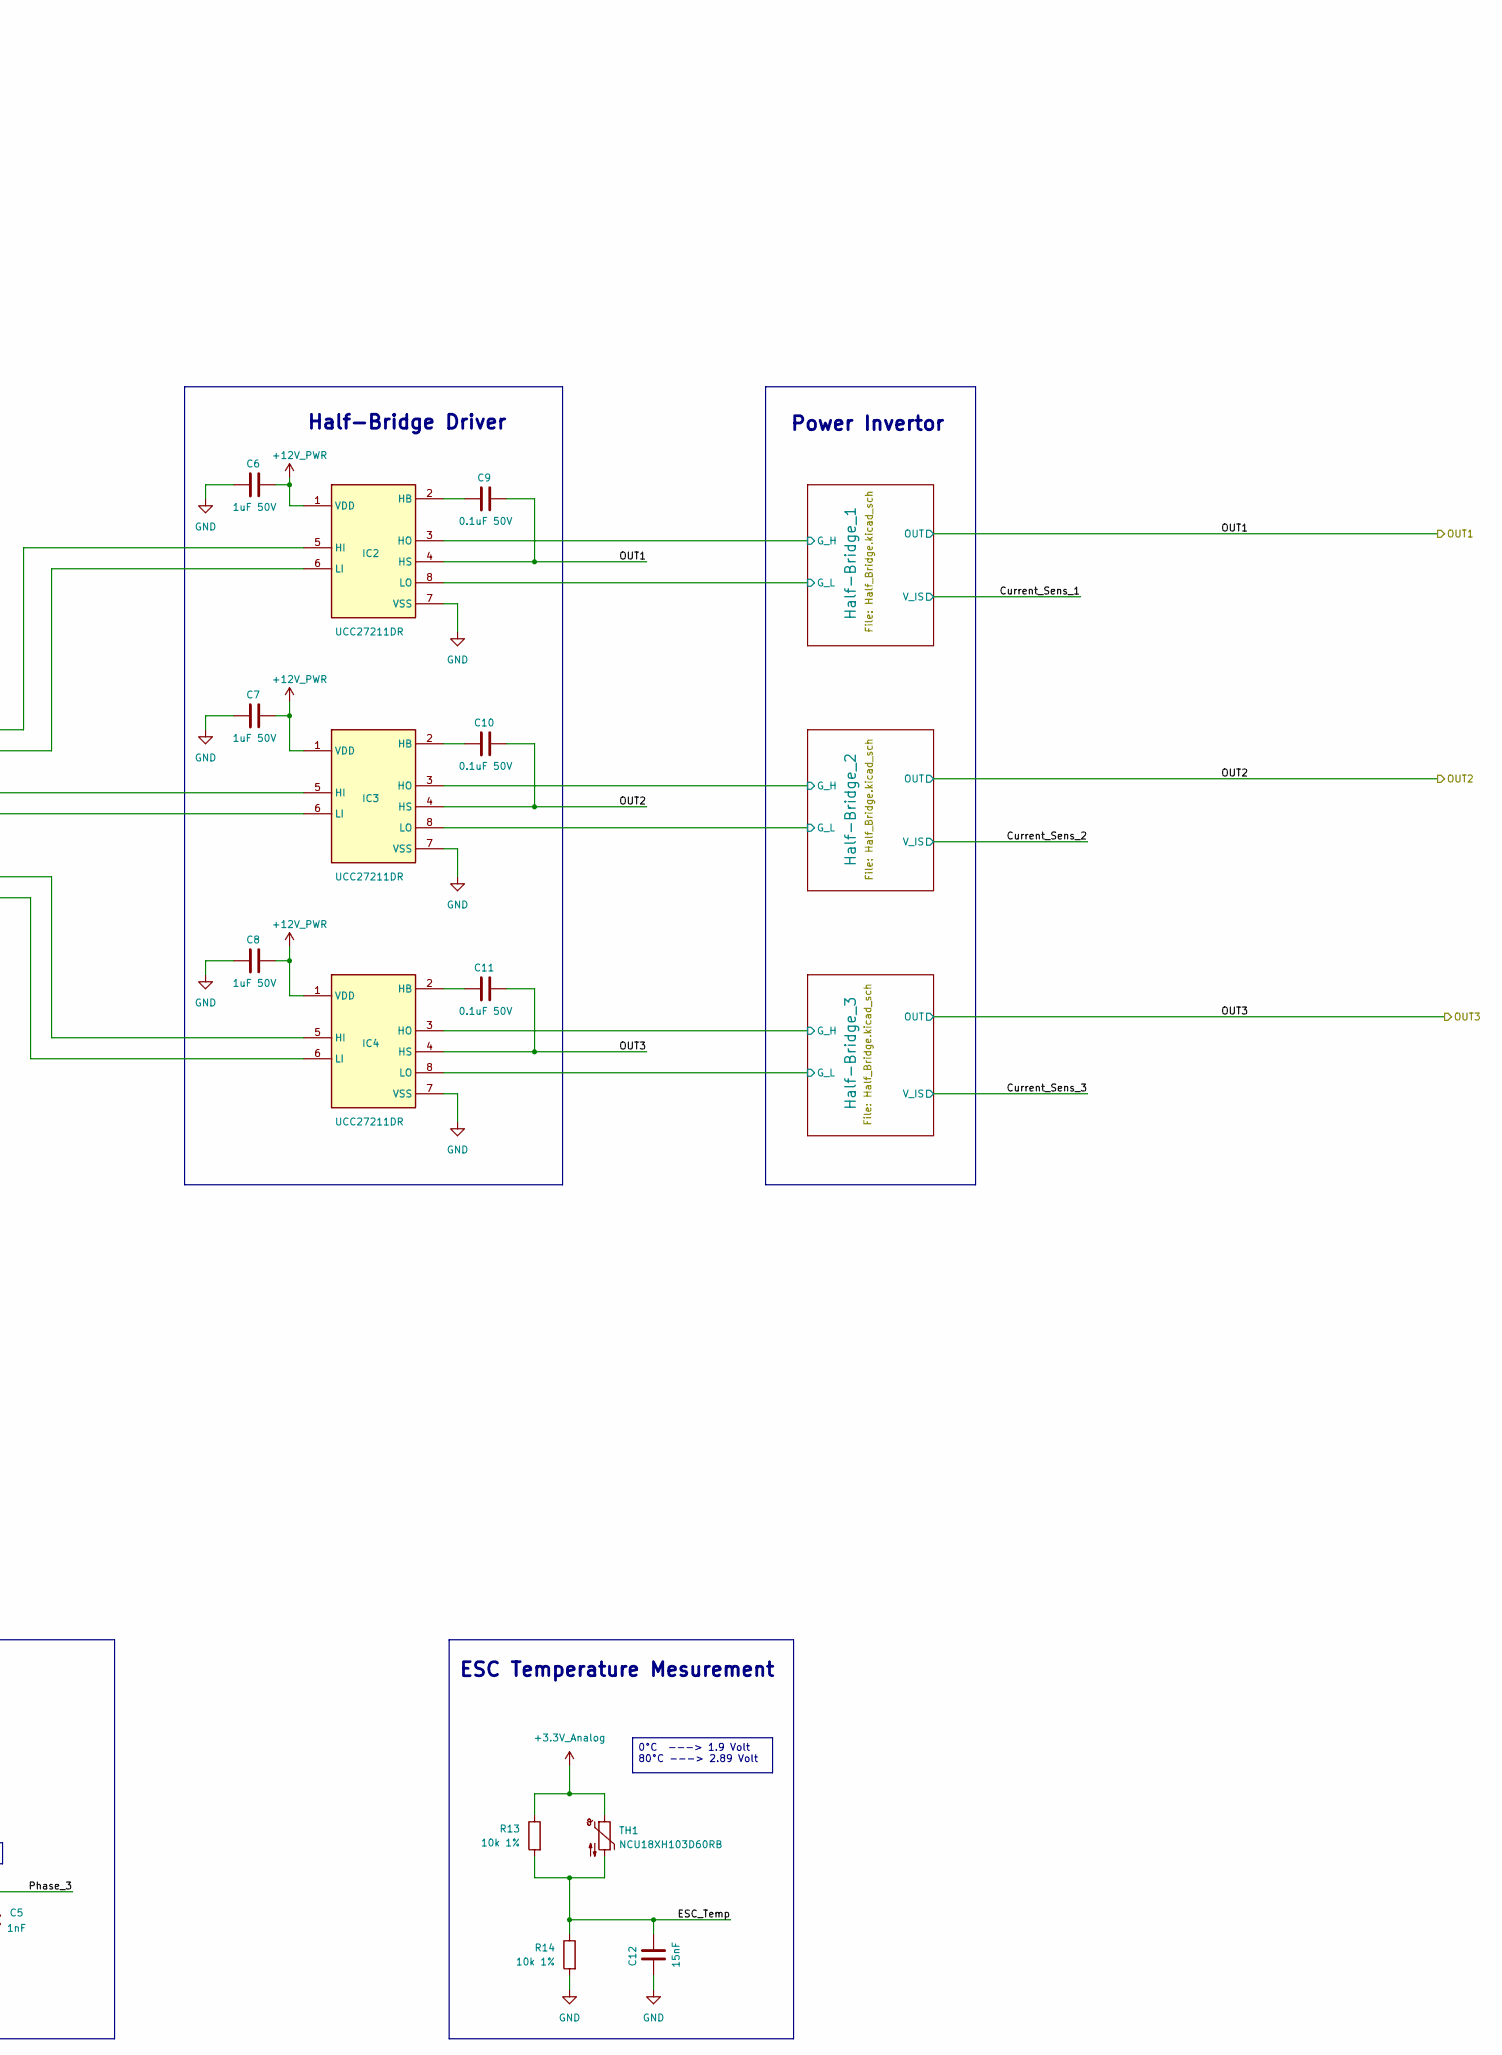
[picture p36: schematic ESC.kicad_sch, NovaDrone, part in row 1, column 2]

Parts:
C1, C3, C5: 1nF; C_0603_1608Metric; Manufacturer_Part_Number KAF15AR71H102KM
C2, C4, C6, C7, C8: 1uF 50V; C_0805_2012Metric; Manufacturer_Part_Number CL21B105KBFNNNE
C9, C10, C11: 0.1uF 50V; C_0603_1608Metric; Manufacturer_Part_Number CL10B104KB85PNL
C12: 15nF; C_0603_1608Metric; Manufacturer_Part_Number CL10B153KB8NNNC
D4, D6, D7: SS0540_R1_00001; SOD3816X135N; Mouser Part Number 241-SS0540_R1_00001
D5: PESD3V3S2UT,215; SOT95P230X110-3N; Mouser Part Number 771-PESD3V3S2UT-T/R
IC1: TCAN3403DDFRQ1; SOT65P280X110-8N; Mouser Part Number 595-TCAN3403DDFRQ1
IC2, IC3, IC4: UCC27211DR; SOIC127P600X175-8N; Mouser Part Number 595-UCC27211DR
J8: JST SH 5Pin; JST_BM05B-SRSS-TB_LF__SN_; PARTREV N/A
J9: JST SH 3Pin; JST_BM03B-SRSS-TB_LF__SN_; PARTREV N/A
R2, R7, R10: 33k 1%; R_0603_1608Metric; Manufacturer_Part_Number AC0603FR-1333KL
R3, R8, R11: 4.7k 1%; R_0603_1608Metric; Manufacturer_Part_Number AF0603FR-074K7L
R4, R9, R12: 51R 1%; R_0603_1608Metric; Manufacturer_Part_Number RT0603FRE0751RL
R5, R6: 22R 1%; R_0603_1608Metric; Manufacturer_Part_Number RT0603FRD0722RL
R13, R14: 10k 1%; R_0603_1608Metric; Manufacturer_Part_Number AF0603FR-0710KL
TH1: NCU18XH103D60RB; R_0603_1608Metric; Manufacturer_Part_Number NCU18XH103D60RB

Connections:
+3.3V_Analog: D4.1 (K), D6.1 (K), D7.1 (K), R13.1, TH1.1; also elsewhere on the board
+3.3V_Digital: C2.1, C4.1, IC1.3 (V_CC), IC1.5 (VIO), J8.1; also elsewhere on the board
+12V_PWR: C6.2, C7.2, C8.2, IC2.1 (VDD), IC3.1 (VDD), IC4.1 (VDD); also elsewhere on the board
/CAN+: IC1.7 (CANH); also elsewhere on the board
/CAN-: IC1.6 (CANL); also elsewhere on the board
/ESC_1/ESC_Temp: C12.2, R13.2, R14.1, TH1.2; also elsewhere on the board
/ESC_1/Half-Bridge_1/G_H: IC2.3 (HO); also elsewhere on the board
/ESC_1/Half-Bridge_1/G_L: IC2.8 (LO); also elsewhere on the board
/ESC_1/Half-Bridge_2/G_H: IC3.3 (HO); also elsewhere on the board
/ESC_1/Half-Bridge_2/G_L: IC3.8 (LO); also elsewhere on the board
/ESC_1/Half-Bridge_3/G_H: IC4.3 (HO); also elsewhere on the board
/ESC_1/Half-Bridge_3/G_L: IC4.8 (LO); also elsewhere on the board
/ESC_1/MCU/FDCAN1_RX: IC1.4 (RXD); also elsewhere on the board
/ESC_1/MCU/FDCAN1_STB: IC1.8 (STB); also elsewhere on the board
/ESC_1/MCU/FDCAN1_TX: IC1.1 (TXD); also elsewhere on the board
/ESC_1/MCU/PWM_A_H: IC2.5 (HI); also elsewhere on the board
/ESC_1/MCU/PWM_A_L: IC2.6 (LI); also elsewhere on the board
/ESC_1/MCU/PWM_B_H: IC3.5 (HI); also elsewhere on the board
/ESC_1/MCU/PWM_B_L: IC3.6 (LI); also elsewhere on the board
/ESC_1/MCU/PWM_C_H: IC4.5 (HI); also elsewhere on the board
/ESC_1/MCU/PWM_C_L: IC4.6 (LI); also elsewhere on the board
/ESC_1/MCU/SWCLK: J8.3; also elsewhere on the board
/ESC_1/MCU/SWDIO: J8.2; also elsewhere on the board
/ESC_1/MCU/UART1_RX: D5.1, R5.2; also elsewhere on the board
/ESC_1/MCU/UART1_TX: D5.2, R6.2; also elsewhere on the board
/ESC_1/OUT1: C9.2, IC2.4 (HS), R2.1; also elsewhere on the board
/ESC_1/OUT2: C10.2, IC3.4 (HS), R7.1; also elsewhere on the board
/ESC_1/OUT3: C11.2, IC4.4 (HS), R10.1; also elsewhere on the board
/ESC_1/Phase_1: C1.2, R4.2; also elsewhere on the board
/ESC_1/Phase_2: C3.2, R9.2; also elsewhere on the board
/ESC_1/Phase_3: C5.2, R12.2; also elsewhere on the board
/ESC_1_nRST: J8.4; also elsewhere on the board
GND: C1.1, C2.2, C3.1, C4.2, C5.1, C6.1, C7.1, C8.1, C12.1, D5.3, IC1.2 (GND), IC2.7 (VSS), IC3.7 (VSS), IC4.7 (VSS), J8.5, J8.S1 (SHIELD), J8.S2 (SHIELD), J9.2, J9.S1 (SHIELD), J9.S2 (SHIELD), R3.1, R8.1, R11.1, R14.2; also elsewhere on the board
unnamed: D4.2 (A), R2.2, R3.2, R4.1
unnamed: D6.2 (A), R7.2, R8.2, R9.1
unnamed: D7.2 (A), R10.2, R11.2, R12.1
unnamed: C9.1, IC2.2 (HB)
unnamed: C10.1, IC3.2 (HB)
unnamed: C11.1, IC4.2 (HB)
unnamed: J9.1, R5.1
unnamed: J9.3, R6.1

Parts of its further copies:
C13, C15, C17, C61, C63, C65, C109, C111, C113: 1nF; C_0603_1608Metric; Manufacturer_Part_Number KAF15AR71H102KM
C14, C16, C18, C19, C20, C62, C64, C66, C67, C68, C110, C112, C114, C115, C116: 1uF 50V; C_0805_2012Metric; Manufacturer_Part_Number CL21B105KBFNNNE
C21, C22, C23, C69, C70, C71, C117, C118, C119: 0.1uF 50V; C_0603_1608Metric; Manufacturer_Part_Number CL10B104KB85PNL
C24, C72, C120: 15nF; C_0603_1608Metric; Manufacturer_Part_Number CL10B153KB8NNNC
D8, D10, D11, D18, D20, D21, D28, D30, D31: SS0540_R1_00001; SOD3816X135N; Mouser Part Number 241-SS0540_R1_00001
D9, D19, D29: PESD3V3S2UT,215; SOT95P230X110-3N; Mouser Part Number 771-PESD3V3S2UT-T/R
IC5, IC13, IC21: TCAN3403DDFRQ1; SOT65P280X110-8N; Mouser Part Number 595-TCAN3403DDFRQ1
IC6, IC7, IC8, IC14, IC15, IC16, IC22, IC23, IC24: UCC27211DR; SOIC127P600X175-8N; Mouser Part Number 595-UCC27211DR
J10, J12, J14: JST SH 5Pin; JST_BM05B-SRSS-TB_LF__SN_; PARTREV N/A
J11, J13, J15: JST SH 3Pin; JST_BM03B-SRSS-TB_LF__SN_; PARTREV N/A
R15, R20, R23, R73, R78, R81, R131, R136, R139: 33k 1%; R_0603_1608Metric; Manufacturer_Part_Number AC0603FR-1333KL
R16, R21, R24, R74, R79, R82, R132, R137, R140: 4.7k 1%; R_0603_1608Metric; Manufacturer_Part_Number AF0603FR-074K7L
R17, R22, R25, R75, R80, R83, R133, R138, R141: 51R 1%; R_0603_1608Metric; Manufacturer_Part_Number RT0603FRE0751RL
R18, R19, R76, R77, R134, R135: 22R 1%; R_0603_1608Metric; Manufacturer_Part_Number RT0603FRD0722RL
R26, R27, R84, R85, R142, R143: 10k 1%; R_0603_1608Metric; Manufacturer_Part_Number AF0603FR-0710KL
TH2, TH3, TH4: NCU18XH103D60RB; R_0603_1608Metric; Manufacturer_Part_Number NCU18XH103D60RB

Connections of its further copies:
+3.3V_Analog: D8.1 (K), D10.1 (K), D11.1 (K), D18.1 (K), D20.1 (K), D21.1 (K), D28.1 (K), D30.1 (K), D31.1 (K), R26.1, R84.1, R142.1, TH2.1, TH3.1, TH4.1; also elsewhere on the board
+3.3V_Digital: C14.1, C16.1, C62.1, C64.1, C110.1, C112.1, IC5.3 (V_CC), IC5.5 (VIO), IC13.3 (V_CC), IC13.5 (VIO), IC21.3 (V_CC), IC21.5 (VIO), J10.1, J12.1, J14.1; also elsewhere on the board
+12V_PWR: C18.2, C19.2, C20.2, C66.2, C67.2, C68.2, C114.2, C115.2, C116.2, IC6.1 (VDD), IC7.1 (VDD), IC8.1 (VDD), IC14.1 (VDD), IC15.1 (VDD), IC16.1 (VDD), IC22.1 (VDD), IC23.1 (VDD), IC24.1 (VDD); also elsewhere on the board
/CAN+: IC5.7 (CANH), IC13.7 (CANH), IC21.7 (CANH); also elsewhere on the board
/CAN-: IC5.6 (CANL), IC13.6 (CANL), IC21.6 (CANL); also elsewhere on the board
/ESC_2/ESC_Temp: C24.2, R26.2, R27.1, TH2.2; also elsewhere on the board
/ESC_2/Half-Bridge_1/G_H: IC6.3 (HO); also elsewhere on the board
/ESC_2/Half-Bridge_1/G_L: IC6.8 (LO); also elsewhere on the board
/ESC_2/Half-Bridge_2/G_H: IC7.3 (HO); also elsewhere on the board
/ESC_2/Half-Bridge_2/G_L: IC7.8 (LO); also elsewhere on the board
/ESC_2/Half-Bridge_3/G_H: IC8.3 (HO); also elsewhere on the board
/ESC_2/Half-Bridge_3/G_L: IC8.8 (LO); also elsewhere on the board
/ESC_2/MCU/FDCAN1_RX: IC5.4 (RXD); also elsewhere on the board
/ESC_2/MCU/FDCAN1_STB: IC5.8 (STB); also elsewhere on the board
/ESC_2/MCU/FDCAN1_TX: IC5.1 (TXD); also elsewhere on the board
/ESC_2/MCU/PWM_A_H: IC6.5 (HI); also elsewhere on the board
/ESC_2/MCU/PWM_A_L: IC6.6 (LI); also elsewhere on the board
/ESC_2/MCU/PWM_B_H: IC7.5 (HI); also elsewhere on the board
/ESC_2/MCU/PWM_B_L: IC7.6 (LI); also elsewhere on the board
/ESC_2/MCU/PWM_C_H: IC8.5 (HI); also elsewhere on the board
/ESC_2/MCU/PWM_C_L: IC8.6 (LI); also elsewhere on the board
/ESC_2/MCU/SWCLK: J10.3; also elsewhere on the board
/ESC_2/MCU/SWDIO: J10.2; also elsewhere on the board
/ESC_2/MCU/UART1_RX: D9.1, R18.2; also elsewhere on the board
/ESC_2/MCU/UART1_TX: D9.2, R19.2; also elsewhere on the board
/ESC_2/OUT1: C21.2, IC6.4 (HS), R15.1; also elsewhere on the board
/ESC_2/OUT2: C22.2, IC7.4 (HS), R20.1; also elsewhere on the board
/ESC_2/OUT3: C23.2, IC8.4 (HS), R23.1; also elsewhere on the board
/ESC_2/Phase_1: C13.2, R17.2; also elsewhere on the board
/ESC_2/Phase_2: C15.2, R22.2; also elsewhere on the board
/ESC_2/Phase_3: C17.2, R25.2; also elsewhere on the board
/ESC_2_nRST: J10.4; also elsewhere on the board
/ESC_3/ESC_Temp: C72.2, R84.2, R85.1, TH3.2; also elsewhere on the board
/ESC_3/Half-Bridge_1/G_H: IC14.3 (HO); also elsewhere on the board
/ESC_3/Half-Bridge_1/G_L: IC14.8 (LO); also elsewhere on the board
/ESC_3/Half-Bridge_2/G_H: IC15.3 (HO); also elsewhere on the board
/ESC_3/Half-Bridge_2/G_L: IC15.8 (LO); also elsewhere on the board
/ESC_3/Half-Bridge_3/G_H: IC16.3 (HO); also elsewhere on the board
/ESC_3/Half-Bridge_3/G_L: IC16.8 (LO); also elsewhere on the board
/ESC_3/MCU/FDCAN1_RX: IC13.4 (RXD); also elsewhere on the board
/ESC_3/MCU/FDCAN1_STB: IC13.8 (STB); also elsewhere on the board
/ESC_3/MCU/FDCAN1_TX: IC13.1 (TXD); also elsewhere on the board
/ESC_3/MCU/PWM_A_H: IC14.5 (HI); also elsewhere on the board
/ESC_3/MCU/PWM_A_L: IC14.6 (LI); also elsewhere on the board
/ESC_3/MCU/PWM_B_H: IC15.5 (HI); also elsewhere on the board
/ESC_3/MCU/PWM_B_L: IC15.6 (LI); also elsewhere on the board
/ESC_3/MCU/PWM_C_H: IC16.5 (HI); also elsewhere on the board
/ESC_3/MCU/PWM_C_L: IC16.6 (LI); also elsewhere on the board
/ESC_3/MCU/SWCLK: J12.3; also elsewhere on the board
/ESC_3/MCU/SWDIO: J12.2; also elsewhere on the board
/ESC_3/MCU/UART1_RX: D19.1, R76.2; also elsewhere on the board
/ESC_3/MCU/UART1_TX: D19.2, R77.2; also elsewhere on the board
/ESC_3/OUT1: C69.2, IC14.4 (HS), R73.1; also elsewhere on the board
/ESC_3/OUT2: C70.2, IC15.4 (HS), R78.1; also elsewhere on the board
/ESC_3/OUT3: C71.2, IC16.4 (HS), R81.1; also elsewhere on the board
/ESC_3/Phase_1: C61.2, R75.2; also elsewhere on the board
/ESC_3/Phase_2: C63.2, R80.2; also elsewhere on the board
/ESC_3/Phase_3: C65.2, R83.2; also elsewhere on the board
/ESC_3_nRST: J12.4; also elsewhere on the board
/ESC_4/ESC_Temp: C120.2, R142.2, R143.1, TH4.2; also elsewhere on the board
/ESC_4/Half-Bridge_1/G_H: IC22.3 (HO); also elsewhere on the board
/ESC_4/Half-Bridge_1/G_L: IC22.8 (LO); also elsewhere on the board
/ESC_4/Half-Bridge_2/G_H: IC23.3 (HO); also elsewhere on the board
/ESC_4/Half-Bridge_2/G_L: IC23.8 (LO); also elsewhere on the board
/ESC_4/Half-Bridge_3/G_H: IC24.3 (HO); also elsewhere on the board
/ESC_4/Half-Bridge_3/G_L: IC24.8 (LO); also elsewhere on the board
/ESC_4/MCU/FDCAN1_RX: IC21.4 (RXD); also elsewhere on the board
/ESC_4/MCU/FDCAN1_STB: IC21.8 (STB); also elsewhere on the board
/ESC_4/MCU/FDCAN1_TX: IC21.1 (TXD); also elsewhere on the board
/ESC_4/MCU/PWM_A_H: IC22.5 (HI); also elsewhere on the board
/ESC_4/MCU/PWM_A_L: IC22.6 (LI); also elsewhere on the board
/ESC_4/MCU/PWM_B_H: IC23.5 (HI); also elsewhere on the board
/ESC_4/MCU/PWM_B_L: IC23.6 (LI); also elsewhere on the board
/ESC_4/MCU/PWM_C_H: IC24.5 (HI); also elsewhere on the board
/ESC_4/MCU/PWM_C_L: IC24.6 (LI); also elsewhere on the board
/ESC_4/MCU/SWCLK: J14.3; also elsewhere on the board
/ESC_4/MCU/SWDIO: J14.2; also elsewhere on the board
/ESC_4/MCU/UART1_RX: D29.1, R134.2; also elsewhere on the board
/ESC_4/MCU/UART1_TX: D29.2, R135.2; also elsewhere on the board
/ESC_4/OUT1: C117.2, IC22.4 (HS), R131.1; also elsewhere on the board
/ESC_4/OUT2: C118.2, IC23.4 (HS), R136.1; also elsewhere on the board
/ESC_4/OUT3: C119.2, IC24.4 (HS), R139.1; also elsewhere on the board
/ESC_4/Phase_1: C109.2, R133.2; also elsewhere on the board
/ESC_4/Phase_2: C111.2, R138.2; also elsewhere on the board
/ESC_4/Phase_3: C113.2, R141.2; also elsewhere on the board
/ESC_4_nRST: J14.4; also elsewhere on the board
GND: C13.1, C14.2, C15.1, C16.2, C17.1, C18.1, C19.1, C20.1, C24.1, C61.1, C62.2, C63.1, C64.2, C65.1, C66.1, C67.1, C68.1, C72.1, C109.1, C110.2, C111.1, C112.2, C113.1, C114.1, C115.1, C116.1, C120.1, D9.3, D19.3, D29.3, IC5.2 (GND), IC6.7 (VSS), IC7.7 (VSS), IC8.7 (VSS), IC13.2 (GND), IC14.7 (VSS), IC15.7 (VSS), IC16.7 (VSS), IC21.2 (GND), IC22.7 (VSS), IC23.7 (VSS), IC24.7 (VSS), J10.5, J10.S1 (SHIELD), J10.S2 (SHIELD), J11.2, J11.S1 (SHIELD), J11.S2 (SHIELD), J12.5, J12.S1 (SHIELD), J12.S2 (SHIELD), J13.2, J13.S1 (SHIELD), J13.S2 (SHIELD), J14.5, J14.S1 (SHIELD), J14.S2 (SHIELD), J15.2, J15.S1 (SHIELD), J15.S2 (SHIELD), R16.1, R21.1, R24.1, R27.2, R74.1, R79.1, R82.1, R85.2, R132.1, R137.1, R140.1, R143.2; also elsewhere on the board
unnamed: D8.2 (A), R15.2, R16.2, R17.1
unnamed: D10.2 (A), R20.2, R21.2, R22.1
unnamed: D11.2 (A), R23.2, R24.2, R25.1
unnamed: D18.2 (A), R73.2, R74.2, R75.1
unnamed: D20.2 (A), R78.2, R79.2, R80.1
unnamed: D21.2 (A), R81.2, R82.2, R83.1
unnamed: D28.2 (A), R131.2, R132.2, R133.1
unnamed: D30.2 (A), R136.2, R137.2, R138.1
unnamed: D31.2 (A), R139.2, R140.2, R141.1
unnamed: C21.1, IC6.2 (HB)
unnamed: C22.1, IC7.2 (HB)
unnamed: C23.1, IC8.2 (HB)
unnamed: C69.1, IC14.2 (HB)
unnamed: C70.1, IC15.2 (HB)
unnamed: C71.1, IC16.2 (HB)
unnamed: C117.1, IC22.2 (HB)
unnamed: C118.1, IC23.2 (HB)
unnamed: C119.1, IC24.2 (HB)
unnamed: J11.1, R18.1
unnamed: J11.3, R19.1
unnamed: J13.1, R76.1
unnamed: J13.3, R77.1
unnamed: J15.1, R134.1
unnamed: J15.3, R135.1

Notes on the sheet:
UART Interface
FD-CAN Interface
Back-EMF Sensing
ESC Temperature Mesurement
Power Invertor
Programming Interface (SWD)
Half-Bridge Driver
Fc = 3.1Mhz
0°C ---> 1.9 Volt 80°C ---> 2.89 Volt
The voltage ragne from: Out : 0V to +22V2 Phase: 0V to 2.76V Ration: 1:8 Fc = 38.7khz : cut-off frequence of the entire chain


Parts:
C205, C212, C225, C231: 15nF; C_0603_1608Metric; Manufacturer_Part_Number CL10B153KB8NNNC
C207, C208, C209: 10uF 63V; C_1210_3225Metric; Manufacturer_Part_Number CL32B106KMVNNWE
C213, C214, C215, C230: 0.1uF 50V; C_0603_1608Metric; Manufacturer_Part_Number CL10B104KB85PNL
C217: 56pF 50V; C_0603_1608Metric; Manufacturer_Part_Number CL10C560JB8NNNC
C218, C219, C221, C222, C226, C227, C229: 22uF 25V; C_1210_3225Metric; Manufacturer_Part_Number CL32B226KAJNNNE
D47, D48: SS0540_R1_00001; SOD3816X135N; Mouser Part Number 241-SS0540_R1_00001
FB2: FerriteBead; L_0805_2012Metric; Manufacturer_Part_Number MPZ2012S601AT000
IC34: AP63205WU-7; AP63205WU7; Mouser Part Number 621-AP63205WU-7
IC35: AP63203WU-7; AP63203WU7; Mouser Part Number 621-AP63203WU-7
J16, J17, J18: B2B-PH-K-S; JST_B2B-PH-K-S
L3: 4.7uH 2.9A 20%; ASPI-4030S; Mouser Part Number 815-ASPI-4030S-4R7MT
L4: 10uH 2.2A 20%; BWVS00505040100M00; Manufacturer_Part_Number BWVS00505040100M00
L5: 3.9uH 3A, 20%; ASPI0628150MT1; Mouser Part Number 815-ASPI-0628-3R9MT1
LED17: RED LED; LEDM168X80N; Manufacturer_Part_Number APHD1608LSURCK
LED18, LED19, LED20: GREEN; LEDM168X80N; Mouser Part Number 604-APHD1608LZGCK
PS2: AP63200WU-7; SOT95P280X100-6N; Mouser Part Number 621-AP63200WU-7
R237: 180k 1%; R_0603_1608Metric; Manufacturer_Part_Number RT0603FRE07180KL
R238, R256, R261, R262: 18k 1%; R_0603_1608Metric; Manufacturer_Part_Number AC0603FR-1318KL
R248, R253: 68k 1%; R_0603_1608Metric; Manufacturer_Part_Number RC0603FR-1068KL
R249: 10k 1%; R_0603_1608Metric; Manufacturer_Part_Number AF0603FR-0710KL
R252: 100k 1%; R_0603_1608Metric; Manufacturer_Part_Number AT0603FRE07100KL
R255: 249k 1%; R_0603_1608Metric; Manufacturer_Part_Number AF0603FR-07249KL
R258: 0.22R 1%; R_0805_2012Metric; Manufacturer_Part_Number RL0805FR-7W0R22L
R259, R260: 33k 1%; R_0603_1608Metric; Manufacturer_Part_Number AC0603FR-1333KL
R263: 6.8k 1%; R_0603_1608Metric; Manufacturer_Part_Number AC0603FR-076K8L
R264: 2k 1%; R_0603_1608Metric; Manufacturer_Part_Number RE0603FRE072KL
TP11: TestPoint; TestPoint_Pad_D1.0mm

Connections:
+3.3V_Logic: C219.2, C222.2, FB2.1, IC35.1 (FB), J18.1, L5.2, R264.1
+3.3V_Logic_filtered: C229.2, C230.2, D47.1 (K), D48.1 (K), R258.1, R259.2, TP11.1; also elsewhere on the board
+5V_Logic: C218.2, C221.2, IC34.1 (FB), J17.1, L3.2, R252.2, R263.1
+12V_Logic: C217.2, C226.2, C227.2, J16.1, L4.2, R248.2, R255.2, R262.1
/+Vbat: C207.2, C208.2, C209.2, IC34.2 (EN), IC34.3 (VIN), IC35.2 (EN), IC35.3 (VIN), PS2.2 (EN), PS2.3 (VIN), R237.2, R261.1; also elsewhere on the board
/Logic PSU/SW: C214.1, L4.1, PS2.5 (SW)
/Logic PSU/V3.3Logic_Mesure: C231.2, R259.1, R260.2; also elsewhere on the board
/Logic PSU/V5Logic_Mesure: C225.2, R252.1, R253.2; also elsewhere on the board
/Logic PSU/V12Logic_Mesure: C212.2, D48.2 (A), R248.1, R249.1; also elsewhere on the board
/Logic PSU/Vbat_Mesure: C205.2, D47.2 (A), R237.1, R238.2; also elsewhere on the board
GND: C205.1, C207.1, C208.1, C209.1, C212.1, C218.1, C219.1, C221.1, C222.1, C225.1, C226.1, C227.1, C229.1, C230.1, C231.1, IC34.4 (GND), IC35.4 (GND), J16.2 (N), J17.2 (N), J18.2 (N), LED17.1 (K), LED18.1 (K), LED19.1 (K), LED20.1 (K), PS2.4 (GND), R238.1, R249.2, R253.1, R256.1, R260.1; also elsewhere on the board
unnamed: FB2.2, R258.2
unnamed: C213.2, IC34.6 (BST)
unnamed: C213.1, IC34.5 (SW), L3.1
unnamed: C215.2, IC35.6 (BST)
unnamed: C215.1, IC35.5 (SW), L5.1
unnamed: LED17.2 (A), R261.2
unnamed: LED18.2 (A), R262.2
unnamed: LED19.2 (A), R263.2
unnamed: LED20.2 (A), R264.2
unnamed: C214.2, PS2.6 (BST)
unnamed: C217.1, PS2.1 (FB), R255.1, R256.2

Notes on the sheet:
Battery Voltage Mesurement
+3.3V_Logic_filtered Mesurement
5V Logic, 2A Max
Connectors
+12V_Logic Mesurement
+5V_Logic Mesurement
3.3V Logic, 2A Max
12V Logic, 2A Max

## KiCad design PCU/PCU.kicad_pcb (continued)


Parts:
C157, C158, C176, C177: 10uF 63V; C_1210_3225Metric; Manufacturer_Part_Number CL32B106KMVNNWE
C159, C162, C165, C168, C169, C172, C174, C175: GXC1V331MCW1GS; CAPAE1030X1300N; Mouser Part Number 647-GXC1V331MCW1GS
C160, C161, C164: 0.1uF 50V; C_0603_1608Metric; Manufacturer_Part_Number CL10B104KB85PNL
C163, C167, C170, C171, C173: 22uF 25V; C_1210_3225Metric; Manufacturer_Part_Number CL32B226KAJNNNE
C166: 56pF 50V; C_0603_1608Metric; Manufacturer_Part_Number CL10C560JB8NNNC
C178, C179, C180: 15nF; C_0603_1608Metric; Manufacturer_Part_Number CL10B153KB8NNNC
D38, D39, D40, D41: SS0540_R1_00001; SOD3816X135N; Mouser Part Number 241-SS0540_R1_00001
FB1: FerriteBead; L_0805_2012Metric; Manufacturer_Part_Number MPZ2012S601AT000
IC29: AP63203WU-7; AP63203WU7; Mouser Part Number 621-AP63203WU-7
L1: 10uH 2.2A 20%; BWVS00505040100M00; Manufacturer_Part_Number BWVS00505040100M00
L2: 3.9uH 3A, 20%; ASPI0628150MT1; Mouser Part Number 815-ASPI-0628-3R9MT1
LED10: RED LED; LEDM168X80N; Manufacturer_Part_Number APHD1608LSURCK
LED11: BLUE; LEDM168X80N; Mouser Part Number 604-APHD1608LQBCD
LED12: GREEN; LEDM168X80N; Mouser Part Number 604-APHD1608LZGCK
PS1: AP63200WU-7; SOT95P280X100-6N; Mouser Part Number 621-AP63200WU-7
R189: 0.22R 1%; R_0805_2012Metric; Manufacturer_Part_Number RL0805FR-7W0R22L
R190: 249k 1%; R_0603_1608Metric; Manufacturer_Part_Number AF0603FR-07249KL
R191, R196, R200: 18k 1%; R_0603_1608Metric; Manufacturer_Part_Number AC0603FR-1318KL
R192, R193: 33k 1%; R_0603_1608Metric; Manufacturer_Part_Number AC0603FR-1333KL
R194: 68k 1%; R_0603_1608Metric; Manufacturer_Part_Number RC0603FR-1068KL
R195, R197: 10k 1%; R_0603_1608Metric; Manufacturer_Part_Number AF0603FR-0710KL
R198: 2k 1%; R_0603_1608Metric; Manufacturer_Part_Number RE0603FRE072KL
R199: 180k 1%; R_0603_1608Metric; Manufacturer_Part_Number RT0603FRE07180KL
TP4, TP5, TP6: TestPoint; TestPoint_Pad_D1.0mm

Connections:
+3.3V_Analog: C163.2, C164.2, D39.2 (A), R189.1, TP5.1; also elsewhere on the board
+3.3V_Digital: C167.2, C170.2, D39.1 (K), D40.1 (K), D41.1 (K), FB1.1, IC29.1 (FB), L2.2, R192.2, R198.1, TP4.1; also elsewhere on the board
+12V_PWR: C166.2, C171.2, C173.2, L1.2, R190.2, R194.2, R197.1, TP6.1; also elsewhere on the board
+Vbus: C157.2, C158.2, C159.1 (+), C162.1 (+), C165.1 (+), C168.1 (+), C169.1 (+), C172.1 (+), C174.1 (+), C175.1 (+), C176.2, C177.2, D38.1 (K), IC29.2 (EN), IC29.3 (VIN), PS1.2 (EN), PS1.3 (VIN), R196.1, R199.2; also elsewhere on the board
/HIGH PSU/SW: C161.1, L1.1, PS1.5 (SW)
/HIGH PSU/V3.3_Mesure: C178.2, R192.1, R193.2; also elsewhere on the board
/HIGH PSU/V12_Mesure: C179.2, D40.2 (A), R194.1, R195.1; also elsewhere on the board
/HIGH PSU/Vbus_Mesure: C180.2, D41.2 (A), R199.1, R200.2; also elsewhere on the board
GND: C157.1, C158.1, C159.2 (-), C162.2 (-), C163.1, C164.1, C165.2 (-), C167.1, C168.2 (-), C169.2 (-), C170.1, C171.1, C172.2 (-), C173.1, C174.2 (-), C175.2 (-), C176.1, C177.1, C178.1, C179.1, C180.1, D38.2 (A), IC29.4 (GND), LED10.1 (K), LED11.1 (K), LED12.1 (K), PS1.4 (GND), R191.1, R193.1, R195.2, R200.1; also elsewhere on the board
unnamed: FB1.2, R189.2
unnamed: C160.2, IC29.6 (BST)
unnamed: C160.1, IC29.5 (SW), L2.1
unnamed: LED10.2 (A), R196.2
unnamed: LED11.2 (A), R197.2
unnamed: LED12.2 (A), R198.2
unnamed: C161.2, PS1.6 (BST)
unnamed: C166.1, PS1.1 (FB), R190.1, R191.2

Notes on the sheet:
+3.3V_Digital Mesurement
Voltage Bus Mesurement
+12V_PWR Mesurement


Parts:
C25, C29: 15nF; C_0603_1608Metric; Manufacturer_Part_Number CL10B153KB8NNNC
C26, C31: 0.1uF 50V; C_0603_1608Metric; Manufacturer_Part_Number CL10B104KB85PNL
C27, C30: 1uF 50V; C_0805_2012Metric; Manufacturer_Part_Number CL21B105KBFNNNE
C28, C32: 1nF; C_0603_1608Metric; Manufacturer_Part_Number KAF15AR71H102KM
D12, D13: SS0540_R1_00001; SOD3816X135N; Mouser Part Number 241-SS0540_R1_00001
IC9: LM321LVIDBVR; SOT95P280X145-5N; Mouser Part Number 595-LM321LVIDBVR
Q1, Q2: SQJA06EP-T1_GE3; SQJ402EPT1; Manufacturer_Part_Number SQJA06EP-T1_GE3
R28, R29: 33k 1%; R_0603_1608Metric; Manufacturer_Part_Number AC0603FR-1333KL
R30, R31: 33R 1%; R_0603_1608Metric; Manufacturer_Part_Number AF0603FR-0733RL
R32, R33, R37, R38: 10R 1%; R_0603_1608Metric; Manufacturer_Part_Number RE0603FRE0710RL
R34, R35: 10k 1%; R_0603_1608Metric; Manufacturer_Part_Number AF0603FR-0710KL
R36: 0.005R 1% 3W; R_2512_6332Metric; Manufacturer_Part_Number MSMA2512R0050FGM
R39: 1R 1%; R_0603_1608Metric; Manufacturer_Part_Number AF0603FR-071RL
R40: 51R 1%; R_0603_1608Metric; Manufacturer_Part_Number RT0603FRE0751RL
U1: INA181A1IDBVR; SOT95P280X145-6N; Mouser Part Number 595-INA181A1IDBVR

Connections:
+3.3V_Analog: C26.1, C30.1, C31.1, IC9.5 (V+), R28.2, U1.6 (VS); also elsewhere on the board
+Vbus: C27.1, Q1.5; also elsewhere on the board
/ESC_2/Current_Sens_2: C32.2, R40.2; also elsewhere on the board
/ESC_2/Half-Bridge_2/G_H: D13.1 (K), R30.1; also elsewhere on the board
/ESC_2/Half-Bridge_2/G_L: D12.1 (K), R31.1; also elsewhere on the board
/ESC_2/Half-Bridge_2/Ref: IC9.3 (IN-), IC9.4 (OUT), U1.5 (REF)
/ESC_2/OUT2: Q1.1, Q1.2, Q1.3, Q2.5, R34.2, R39.1; also elsewhere on the board
GND: C25.1, C26.2, C27.2, C29.1, C30.2, C31.2, C32.1, IC9.2 (V-), R29.1, R36.2, R38.1, U1.2 (GND); also elsewhere on the board
unnamed: C29.2, R39.2
unnamed: D12.2 (A), R33.1
unnamed: D13.2 (A), R32.1
unnamed: C25.2, IC9.1 (IN+), R28.1, R29.2
unnamed: Q1.4, R30.2, R32.2, R34.1
unnamed: Q2.1, Q2.2, Q2.3, R35.2, R36.1, R37.1
unnamed: Q2.4, R31.2, R33.2, R35.1
unnamed: C28.2, R37.2, U1.3 (IN+)
unnamed: C28.1, R38.2, U1.4 (IN-)
unnamed: R40.1, U1.1 (OUT)

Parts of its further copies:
C33, C37, C41, C45, C73, C77, C81, C85, C89, C93, C121, C125, C129, C133, C137, C141, C194, C200, C206, C220, C235, C248: 15nF; C_0603_1608Metric; Manufacturer_Part_Number CL10B153KB8NNNC
C34, C39, C42, C47, C74, C79, C82, C87, C90, C95, C122, C127, C130, C135, C138, C143, C195, C202, C210, C224, C237, C251: 0.1uF 50V; C_0603_1608Metric; Manufacturer_Part_Number CL10B104KB85PNL
C35, C38, C43, C46, C75, C78, C83, C86, C91, C94, C123, C126, C131, C134, C139, C142, C197, C201, C211, C223, C240, C250: 1uF 50V; C_0805_2012Metric; Manufacturer_Part_Number CL21B105KBFNNNE
C36, C40, C44, C48, C76, C80, C84, C88, C92, C96, C124, C128, C132, C136, C140, C144, C198, C204, C216, C228, C242, C253: 1nF; C_0603_1608Metric; Manufacturer_Part_Number KAF15AR71H102KM
D14, D15, D16, D17, D22, D23, D24, D25, D26, D27, D32, D33, D34, D35, D36, D37, D42, D43, D45, D46, D49, D50: SS0540_R1_00001; SOD3816X135N; Mouser Part Number 241-SS0540_R1_00001
IC10, IC11, IC17, IC18, IC19, IC25, IC26, IC27, IC31, IC33, IC37: LM321LVIDBVR; SOT95P280X145-5N; Mouser Part Number 595-LM321LVIDBVR
Q3, Q4, Q5, Q6, Q7, Q8, Q9, Q10, Q11, Q12, Q13, Q14, Q15, Q16, Q17, Q18, Q19, Q20, Q28, Q29, Q30, Q31: SQJA06EP-T1_GE3; SQJ402EPT1; Manufacturer_Part_Number SQJA06EP-T1_GE3
R41, R42, R54, R55, R86, R87, R99, R100, R112, R113, R144, R145, R157, R158, R170, R171, R208, R209, R239, R240, R266, R267: 33k 1%; R_0603_1608Metric; Manufacturer_Part_Number AC0603FR-1333KL
R43, R44, R56, R57, R88, R89, R101, R102, R114, R115, R146, R147, R159, R160, R172, R173, R210, R211, R241, R242, R268, R269: 33R 1%; R_0603_1608Metric; Manufacturer_Part_Number AF0603FR-0733RL
R45, R46, R50, R51, R58, R59, R63, R64, R90, R91, R95, R96, R103, R104, R108, R109, R116, R117, R121, R122, R148, R149, R153, R154, R161, R162, R166, R167, R174, R175, R179, R180, R212, R213, R223, R224, R243, R244, R250, R251, R270, R271, R277, R278: 10R 1%; R_0603_1608Metric; Manufacturer_Part_Number RE0603FRE0710RL
R47, R48, R60, R61, R92, R93, R105, R106, R118, R119, R150, R151, R163, R164, R176, R177, R217, R218, R245, R246, R273, R274: 10k 1%; R_0603_1608Metric; Manufacturer_Part_Number AF0603FR-0710KL
R49, R62, R94, R107, R120, R152, R165, R178, R219, R247, R275: 0.005R 1% 3W; R_2512_6332Metric; Manufacturer_Part_Number MSMA2512R0050FGM
R52, R65, R97, R110, R123, R155, R168, R181, R231, R254, R280: 1R 1%; R_0603_1608Metric; Manufacturer_Part_Number AF0603FR-071RL
R53, R66, R98, R111, R124, R156, R169, R182, R234, R257, R281: 51R 1%; R_0603_1608Metric; Manufacturer_Part_Number RT0603FRE0751RL
U2, U3, U4, U5, U6, U7, U8, U9, U10, U11, U12: INA181A1IDBVR; SOT95P280X145-6N; Mouser Part Number 595-INA181A1IDBVR

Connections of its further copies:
+3.3V_Analog: C34.1, C38.1, C39.1, C42.1, C46.1, C47.1, C74.1, C78.1, C79.1, C82.1, C86.1, C87.1, C90.1, C94.1, C95.1, C122.1, C126.1, C127.1, C130.1, C134.1, C135.1, C138.1, C142.1, C143.1, C195.1, C201.1, C202.1, C210.1, C223.1, C224.1, C237.1, C250.1, C251.1, IC10.5 (V+), IC11.5 (V+), IC17.5 (V+), IC18.5 (V+), IC19.5 (V+), IC25.5 (V+), IC26.5 (V+), IC27.5 (V+), IC31.5 (V+), IC33.5 (V+), IC37.5 (V+), R41.2, R54.2, R86.2, R99.2, R112.2, R144.2, R157.2, R170.2, R208.2, R239.2, R266.2, U2.6 (VS), U3.6 (VS), U4.6 (VS), U5.6 (VS), U6.6 (VS), U7.6 (VS), U8.6 (VS), U9.6 (VS), U10.6 (VS), U11.6 (VS), U12.6 (VS); also elsewhere on the board
+Vbus: C35.1, C43.1, C75.1, C83.1, C91.1, C123.1, C131.1, C139.1, C197.1, C211.1, C240.1, Q3.5, Q5.5, Q7.5, Q9.5, Q11.5, Q13.5, Q15.5, Q17.5, Q19.5, Q28.5, Q30.5; also elsewhere on the board
/ESC_1/Current_Sens_1: C204.2, R234.2; also elsewhere on the board
/ESC_1/Current_Sens_2: C228.2, R257.2; also elsewhere on the board
/ESC_1/Current_Sens_3: C253.2, R281.2; also elsewhere on the board
/ESC_1/Half-Bridge_1/G_H: D43.1 (K), R210.1; also elsewhere on the board
/ESC_1/Half-Bridge_1/G_L: D42.1 (K), R211.1; also elsewhere on the board
/ESC_1/Half-Bridge_1/Ref: IC31.3 (IN-), IC31.4 (OUT), U10.5 (REF)
/ESC_1/Half-Bridge_2/G_H: D46.1 (K), R241.1; also elsewhere on the board
/ESC_1/Half-Bridge_2/G_L: D45.1 (K), R242.1; also elsewhere on the board
/ESC_1/Half-Bridge_2/Ref: IC33.3 (IN-), IC33.4 (OUT), U11.5 (REF)
/ESC_1/Half-Bridge_3/G_H: D50.1 (K), R268.1; also elsewhere on the board
/ESC_1/Half-Bridge_3/G_L: D49.1 (K), R269.1; also elsewhere on the board
/ESC_1/Half-Bridge_3/Ref: IC37.3 (IN-), IC37.4 (OUT), U12.5 (REF)
/ESC_1/OUT1: Q19.1, Q19.2, Q19.3, Q20.5, R217.2, R231.1; also elsewhere on the board
/ESC_1/OUT2: Q28.1, Q28.2, Q28.3, Q29.5, R245.2, R254.1; also elsewhere on the board
/ESC_1/OUT3: Q30.1, Q30.2, Q30.3, Q31.5, R273.2, R280.1; also elsewhere on the board
/ESC_2/Current_Sens_1: C40.2, R53.2; also elsewhere on the board
/ESC_2/Current_Sens_3: C48.2, R66.2; also elsewhere on the board
/ESC_2/Half-Bridge_1/G_H: D15.1 (K), R43.1; also elsewhere on the board
/ESC_2/Half-Bridge_1/G_L: D14.1 (K), R44.1; also elsewhere on the board
/ESC_2/Half-Bridge_1/Ref: IC10.3 (IN-), IC10.4 (OUT), U2.5 (REF)
/ESC_2/Half-Bridge_3/G_H: D17.1 (K), R56.1; also elsewhere on the board
/ESC_2/Half-Bridge_3/G_L: D16.1 (K), R57.1; also elsewhere on the board
/ESC_2/Half-Bridge_3/Ref: IC11.3 (IN-), IC11.4 (OUT), U3.5 (REF)
/ESC_2/OUT1: Q3.1, Q3.2, Q3.3, Q4.5, R47.2, R52.1; also elsewhere on the board
/ESC_2/OUT3: Q5.1, Q5.2, Q5.3, Q6.5, R60.2, R65.1; also elsewhere on the board
/ESC_3/Current_Sens_1: C88.2, R111.2; also elsewhere on the board
/ESC_3/Current_Sens_2: C80.2, R98.2; also elsewhere on the board
/ESC_3/Current_Sens_3: C96.2, R124.2; also elsewhere on the board
/ESC_3/Half-Bridge_1/G_H: D25.1 (K), R101.1; also elsewhere on the board
/ESC_3/Half-Bridge_1/G_L: D24.1 (K), R102.1; also elsewhere on the board
/ESC_3/Half-Bridge_1/Ref: IC18.3 (IN-), IC18.4 (OUT), U5.5 (REF)
/ESC_3/Half-Bridge_2/G_H: D23.1 (K), R88.1; also elsewhere on the board
/ESC_3/Half-Bridge_2/G_L: D22.1 (K), R89.1; also elsewhere on the board
/ESC_3/Half-Bridge_2/Ref: IC17.3 (IN-), IC17.4 (OUT), U4.5 (REF)
/ESC_3/Half-Bridge_3/G_H: D27.1 (K), R114.1; also elsewhere on the board
/ESC_3/Half-Bridge_3/G_L: D26.1 (K), R115.1; also elsewhere on the board
/ESC_3/Half-Bridge_3/Ref: IC19.3 (IN-), IC19.4 (OUT), U6.5 (REF)
/ESC_3/OUT1: Q9.1, Q9.2, Q9.3, Q10.5, R105.2, R110.1; also elsewhere on the board
/ESC_3/OUT2: Q7.1, Q7.2, Q7.3, Q8.5, R92.2, R97.1; also elsewhere on the board
/ESC_3/OUT3: Q11.1, Q11.2, Q11.3, Q12.5, R118.2, R123.1; also elsewhere on the board
/ESC_4/Current_Sens_1: C136.2, R169.2; also elsewhere on the board
/ESC_4/Current_Sens_2: C128.2, R156.2; also elsewhere on the board
/ESC_4/Current_Sens_3: C144.2, R182.2; also elsewhere on the board
/ESC_4/Half-Bridge_1/G_H: D35.1 (K), R159.1; also elsewhere on the board
/ESC_4/Half-Bridge_1/G_L: D34.1 (K), R160.1; also elsewhere on the board
/ESC_4/Half-Bridge_1/Ref: IC26.3 (IN-), IC26.4 (OUT), U8.5 (REF)
/ESC_4/Half-Bridge_2/G_H: D33.1 (K), R146.1; also elsewhere on the board
/ESC_4/Half-Bridge_2/G_L: D32.1 (K), R147.1; also elsewhere on the board
/ESC_4/Half-Bridge_2/Ref: IC25.3 (IN-), IC25.4 (OUT), U7.5 (REF)
/ESC_4/Half-Bridge_3/G_H: D37.1 (K), R172.1; also elsewhere on the board
/ESC_4/Half-Bridge_3/G_L: D36.1 (K), R173.1; also elsewhere on the board
/ESC_4/Half-Bridge_3/Ref: IC27.3 (IN-), IC27.4 (OUT), U9.5 (REF)
/ESC_4/OUT1: Q15.1, Q15.2, Q15.3, Q16.5, R163.2, R168.1; also elsewhere on the board
/ESC_4/OUT2: Q13.1, Q13.2, Q13.3, Q14.5, R150.2, R155.1; also elsewhere on the board
/ESC_4/OUT3: Q17.1, Q17.2, Q17.3, Q18.5, R176.2, R181.1; also elsewhere on the board
GND: C33.1, C34.2, C35.2, C37.1, C38.2, C39.2, C40.1, C41.1, C42.2, C43.2, C45.1, C46.2, C47.2, C48.1, C73.1, C74.2, C75.2, C77.1, C78.2, C79.2, C80.1, C81.1, C82.2, C83.2, C85.1, C86.2, C87.2, C88.1, C89.1, C90.2, C91.2, C93.1, C94.2, C95.2, C96.1, C121.1, C122.2, C123.2, C125.1, C126.2, C127.2, C128.1, C129.1, C130.2, C131.2, C133.1, C134.2, C135.2, C136.1, C137.1, C138.2, C139.2, C141.1, C142.2, C143.2, C144.1, C194.1, C195.2, C197.2, C200.1, C201.2, C202.2, C204.1, C206.1, C210.2, C211.2, C220.1, C223.2, C224.2, C228.1, C235.1, C237.2, C240.2, C248.1, C250.2, C251.2, C253.1, IC10.2 (V-), IC11.2 (V-), IC17.2 (V-), IC18.2 (V-), IC19.2 (V-), IC25.2 (V-), IC26.2 (V-), IC27.2 (V-), IC31.2 (V-), IC33.2 (V-), IC37.2 (V-), R42.1, R49.2, R51.1, R55.1, R62.2, R64.1, R87.1, R94.2, R96.1, R100.1, R107.2, R109.1, R113.1, R120.2, R122.1, R145.1, R152.2, R154.1, R158.1, R165.2, R167.1, R171.1, R178.2, R180.1, R209.1, R219.2, R224.1, R240.1, R247.2, R251.1, R267.1, R275.2, R278.1, U2.2 (GND), U3.2 (GND), U4.2 (GND), U5.2 (GND), U6.2 (GND), U7.2 (GND), U8.2 (GND), U9.2 (GND), U10.2 (GND), U11.2 (GND), U12.2 (GND); also elsewhere on the board
unnamed: C37.2, R52.2
unnamed: C45.2, R65.2
unnamed: C77.2, R97.2
unnamed: C85.2, R110.2
unnamed: C93.2, R123.2
unnamed: C125.2, R155.2
unnamed: C133.2, R168.2
unnamed: C141.2, R181.2
unnamed: C200.2, R231.2
unnamed: C220.2, R254.2
unnamed: C248.2, R280.2
unnamed: D14.2 (A), R46.1
unnamed: D15.2 (A), R45.1
unnamed: D16.2 (A), R59.1
unnamed: D17.2 (A), R58.1
unnamed: D22.2 (A), R91.1
unnamed: D23.2 (A), R90.1
unnamed: D24.2 (A), R104.1
unnamed: D25.2 (A), R103.1
unnamed: D26.2 (A), R117.1
unnamed: D27.2 (A), R116.1
unnamed: D32.2 (A), R149.1
unnamed: D33.2 (A), R148.1
unnamed: D34.2 (A), R162.1
unnamed: D35.2 (A), R161.1
unnamed: D36.2 (A), R175.1
unnamed: D37.2 (A), R174.1
unnamed: D42.2 (A), R213.1
unnamed: D43.2 (A), R212.1
unnamed: D45.2 (A), R244.1
unnamed: D46.2 (A), R243.1
unnamed: D49.2 (A), R271.1
unnamed: D50.2 (A), R270.1
unnamed: C33.2, IC10.1 (IN+), R41.1, R42.2
unnamed: C41.2, IC11.1 (IN+), R54.1, R55.2
unnamed: C73.2, IC17.1 (IN+), R86.1, R87.2
unnamed: C81.2, IC18.1 (IN+), R99.1, R100.2
unnamed: C89.2, IC19.1 (IN+), R112.1, R113.2
unnamed: C121.2, IC25.1 (IN+), R144.1, R145.2
unnamed: C129.2, IC26.1 (IN+), R157.1, R158.2
unnamed: C137.2, IC27.1 (IN+), R170.1, R171.2
unnamed: C194.2, IC31.1 (IN+), R208.1, R209.2
unnamed: C206.2, IC33.1 (IN+), R239.1, R240.2
unnamed: C235.2, IC37.1 (IN+), R266.1, R267.2
unnamed: Q3.4, R43.2, R45.2, R47.1
unnamed: Q4.1, Q4.2, Q4.3, R48.2, R49.1, R50.1
unnamed: Q4.4, R44.2, R46.2, R48.1
unnamed: Q5.4, R56.2, R58.2, R60.1
unnamed: Q6.1, Q6.2, Q6.3, R61.2, R62.1, R63.1
unnamed: Q6.4, R57.2, R59.2, R61.1
unnamed: Q7.4, R88.2, R90.2, R92.1
unnamed: Q8.1, Q8.2, Q8.3, R93.2, R94.1, R95.1
unnamed: Q8.4, R89.2, R91.2, R93.1
unnamed: Q9.4, R101.2, R103.2, R105.1
unnamed: Q10.1, Q10.2, Q10.3, R106.2, R107.1, R108.1
unnamed: Q10.4, R102.2, R104.2, R106.1
unnamed: Q11.4, R114.2, R116.2, R118.1
unnamed: Q12.1, Q12.2, Q12.3, R119.2, R120.1, R121.1
unnamed: Q12.4, R115.2, R117.2, R119.1
unnamed: Q13.4, R146.2, R148.2, R150.1
unnamed: Q14.1, Q14.2, Q14.3, R151.2, R152.1, R153.1
unnamed: Q14.4, R147.2, R149.2, R151.1
unnamed: Q15.4, R159.2, R161.2, R163.1
unnamed: Q16.1, Q16.2, Q16.3, R164.2, R165.1, R166.1
unnamed: Q16.4, R160.2, R162.2, R164.1
unnamed: Q17.4, R172.2, R174.2, R176.1
unnamed: Q18.1, Q18.2, Q18.3, R177.2, R178.1, R179.1
unnamed: Q18.4, R173.2, R175.2, R177.1
unnamed: Q19.4, R210.2, R212.2, R217.1
unnamed: Q20.1, Q20.2, Q20.3, R218.2, R219.1, R223.1
unnamed: Q20.4, R211.2, R213.2, R218.1
unnamed: Q28.4, R241.2, R243.2, R245.1
unnamed: Q29.1, Q29.2, Q29.3, R246.2, R247.1, R250.1
unnamed: Q29.4, R242.2, R244.2, R246.1
unnamed: Q30.4, R268.2, R270.2, R273.1
unnamed: Q31.1, Q31.2, Q31.3, R274.2, R275.1, R277.1
unnamed: Q31.4, R269.2, R271.2, R274.1
unnamed: C36.2, R50.2, U2.3 (IN+)
unnamed: C36.1, R51.2, U2.4 (IN-)
unnamed: R53.1, U2.1 (OUT)
unnamed: C44.2, R63.2, U3.3 (IN+)
unnamed: C44.1, R64.2, U3.4 (IN-)
unnamed: R66.1, U3.1 (OUT)
unnamed: C76.2, R95.2, U4.3 (IN+)
unnamed: C76.1, R96.2, U4.4 (IN-)
unnamed: R98.1, U4.1 (OUT)
unnamed: C84.2, R108.2, U5.3 (IN+)
unnamed: C84.1, R109.2, U5.4 (IN-)
unnamed: R111.1, U5.1 (OUT)
unnamed: C92.2, R121.2, U6.3 (IN+)
unnamed: C92.1, R122.2, U6.4 (IN-)
unnamed: R124.1, U6.1 (OUT)
unnamed: C124.2, R153.2, U7.3 (IN+)
unnamed: C124.1, R154.2, U7.4 (IN-)
unnamed: R156.1, U7.1 (OUT)
unnamed: C132.2, R166.2, U8.3 (IN+)
unnamed: C132.1, R167.2, U8.4 (IN-)
unnamed: R169.1, U8.1 (OUT)
unnamed: C140.2, R179.2, U9.3 (IN+)
unnamed: C140.1, R180.2, U9.4 (IN-)
unnamed: R182.1, U9.1 (OUT)
unnamed: C198.2, R223.2, U10.3 (IN+)
unnamed: C198.1, R224.2, U10.4 (IN-)
unnamed: R234.1, U10.1 (OUT)
unnamed: C216.2, R250.2, U11.3 (IN+)
unnamed: C216.1, R251.2, U11.4 (IN-)
unnamed: R257.1, U11.1 (OUT)
unnamed: C242.2, R277.2, U12.3 (IN+)
unnamed: C242.1, R278.2, U12.4 (IN-)
unnamed: R281.1, U12.1 (OUT)

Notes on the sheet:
Fc = 3.1Mhz
The Gain of the Amplifier is 20V/V The maximum current that can be sens is 15A V_IS ----> Volt I ----> Ampere I = Ref + V_IS/(R_sens*20)

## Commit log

2025-07-06 End of Inverter design
    [Half_Bridge.kicad_sch, NovaDrone.kicad_sch]
2025-07-07 PCB temperature measurement
    [Half_Bridge.kicad_sch, NovaDrone.kicad_sch]
2025-07-14 Interfaces Update
    [Half_Bridge.kicad_sch, MCU.kicad_sch, NovaDrone.kicad_sch]
2025-07-18 Power Supply
    [MCU.kicad_sch, NovaDrone.kicad_sch, Power_Supply.kicad_sch]
2025-07-18 Rename project
    [ESC.kicad_pcb, ESC.kicad_sch, Half_Bridge.kicad_sch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]
2025-07-19 Power Supply Update
    [ESC.kicad_sch, Half_Bridge.kicad_sch, MCU.kicad_sch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]
2025-07-21 End of Schematic
    [ESC.kicad_sch, Half_Bridge.kicad_sch, Power_Supply.kicad_sch]
2025-07-21 Start of PCB Layout
    [ESC.kicad_pcb, ESC.kicad_sch, Half_Bridge.kicad_sch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]
2025-07-22 PCB Layout Update
    [ESC.kicad_pcb, Power_Supply.kicad_sch]
2025-08-04 PCB nearly completed
    [ESC.kicad_pcb, ESC.kicad_sch, MCU.kicad_sch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]
2025-08-05 End of Placement
    [ESC.kicad_pcb]
2025-08-06 PCB End of Routing
    [ESC.kicad_pcb]
2025-08-07 End of PCB Routing
    [ESC.kicad_pcb]
2025-08-17 BOM Update
    [ESC.kicad_sch, Half_Bridge.kicad_sch]
2025-11-09 Propulsion Control Unit - Started
    [ESC.kicad_sch, Half_Bridge.kicad_sch, MCU.kicad_sch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]
2025-11-10 ESC Block Updated
    [ESC.kicad_sch, Half_Bridge.kicad_sch, MCU.kicad_sch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]
2025-11-11 high power supply block
    [ESC.kicad_sch, Half_Bridge.kicad_sch, MCU.kicad_sch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]
2025-11-14 Active precharge Block
    [active_precharge.kicad_sch, logic_power_supply.kicad_sch]
2025-11-15 Logic PSU Completed
    [PCU.kicad_sch, Supervisor.kicad_sch, active_precharge.kicad_sch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]
2025-11-16 Supervisor Block
    [ESC.kicad_sch, Half_Bridge.kicad_sch, MCU.kicad_sch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]
2025-11-17 Start of PCB Design
    [ESC.kicad_sch, Half_Bridge.kicad_sch, MCU.kicad_sch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]
2025-11-21 PCB Design started
    [Half_Bridge.kicad_sch, PCU.kicad_pcb, active_precharge.kicad_sch]
2025-11-24 Component Placement
    [PCU.kicad_pcb]
2025-11-25 Precharge Block Routed
    [PCU.kicad_pcb]
2025-11-26 PSU Blocks Routed
    [PCU.kicad_pcb, PCU.kicad_sch, Supervisor.kicad_sch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]
2025-12-01 Power stage routed
    [PCU.kicad_pcb]
2025-12-01 Drivers routed
    [PCU.kicad_pcb]
2025-12-03 All components placed
    [PCU.kicad_pcb, logic_power_supply.kicad_sch]
2025-12-05 Analog Signal Routing started
    [MCU.kicad_sch, PCU.kicad_pcb]
2025-12-06 ESCs Analog signals routed
    [ESC.kicad_sch, MCU.kicad_sch, PCU.kicad_pcb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]
2025-12-06 All analog signals routed
    [PCU.kicad_pcb, Supervisor.kicad_sch]
2025-12-07 Analog trace optimization
    [PCU.kicad_pcb]
2025-12-08 Digital high speed routing started
    [PCU.kicad_pcb, PCU.kicad_sch]
2025-12-09 Gigital high speed signal routed
    [PCU.kicad_pcb]
2025-12-10 PWM Signals routed
    [PCU.kicad_pcb]
2025-12-11 Digital signal routed
    [PCU.kicad_pcb]
2025-12-12 Digital signals routed
    [PCU.kicad_pcb, PCU.kicad_sch, Supervisor.kicad_sch]
2025-12-15 Logic power supply routed
    [PCU.kicad_pcb]
2025-12-17 All track routed
    [PCU.kicad_pcb]
2025-12-19 Silkscreen add
    [PCU.kicad_pcb]
2025-12-20 End of Design
    [PCU.kicad_pcb, PCU.kicad_sch]
2026-01-03 Update connector type from XT90 to XT60
2026-01-03 Components library added
    [4328.step, AP62301Z6-7.stp, AP63200WU-7.stp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]
2026-01-03 Fly controller design started
    [4328.step, AP62301Z6-7.stp, AP63200WU-7.stp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]
2026-02-19 RC Module Added
    [4328.step, AP62301Z6-7.stp, AP63200WU-7.stp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]
2026-02-19 GNSS & Compass Module Added
    [GNSS-Module.kicad_pcb, GNSS-Module.kicad_sch]
2026-02-19 Project Lib Added
    [4328.step, AP62301Z6-7.stp, AP63200WU-7.stp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]

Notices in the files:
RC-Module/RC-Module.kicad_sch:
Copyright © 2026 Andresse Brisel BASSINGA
